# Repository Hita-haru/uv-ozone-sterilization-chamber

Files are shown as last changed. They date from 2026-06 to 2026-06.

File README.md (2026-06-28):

# UV and Ozone Sterilization chamber
## Description
This is a project to build a chamber that sterilizes objects using a UV lamp (wavelength 185 nm) that generates ozone.
## Reason for creating this
Have you ever been bothered by annoying mold or bacteria?
For example, a dishcloth that won’t lose its smell no matter how much you wash it, a lunchbox that goes bad as soon as you leave it out for a bit, a rubber duck toy that gets moldy the moment you leave it in the bathroom, or culture media that gets contaminated no matter how clean you keep it—I think everyone has struggled with these issues at least once.
I decided to create this because I wanted to solve those problems.
## Print settings
We strongly recommend using a high-strength gyroid for the infill!  
At the very least, please avoid using weak infills like Lightning. If you accidentally bump it while using it, it will shatter and emit dangerous UV rays, which is extremely hazardous!  
For the same reason, please set the infill to 25% or higher.  
Also, since we’ll be using insert nuts, set the number of wall lines to 4 or more.  
## Assembly Instructions
1. Wire the components
Please wire the components according to the wiring diagram. However, leave the wiring between the CCFL inverter and the UVC bulb, as well as the reset button (GPIO 4), unconnected.
2. Throw the components into the printed box.
Throw them into the box on the right labeled “Sterilization Chamber” and screw in the rotary encoder and other parts. Be sure to solder the reset button and UVC bulb in place after installing them. Otherwise, you’ll look like an idiot.
3. Glue the boxes together. For the large box, attach the side with the two small holes; for the small box, attach the side without a wall.
4. Insert the insert nuts.
Use a soldering iron or something similar to screw them into the holes. These are located on the bottom of the large lid, the bottom of the large box, the top of the interior, and the back of the small box.
5. Secure them with screws.
## Screenshots
### Prented result (CAD Screenshot)
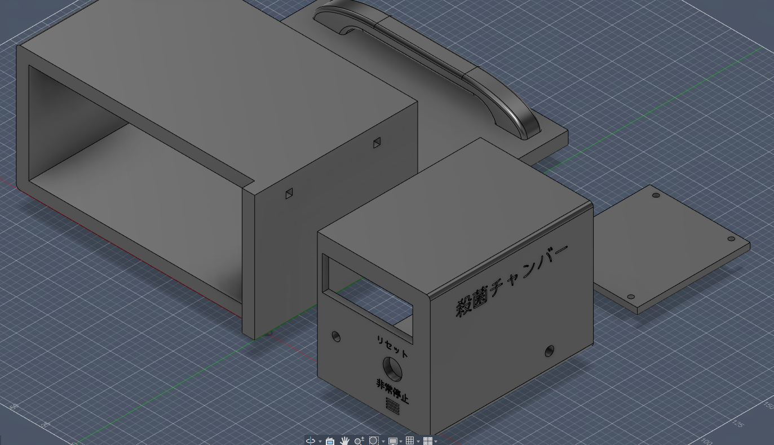
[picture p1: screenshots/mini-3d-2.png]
Printed result

### Writing diagram
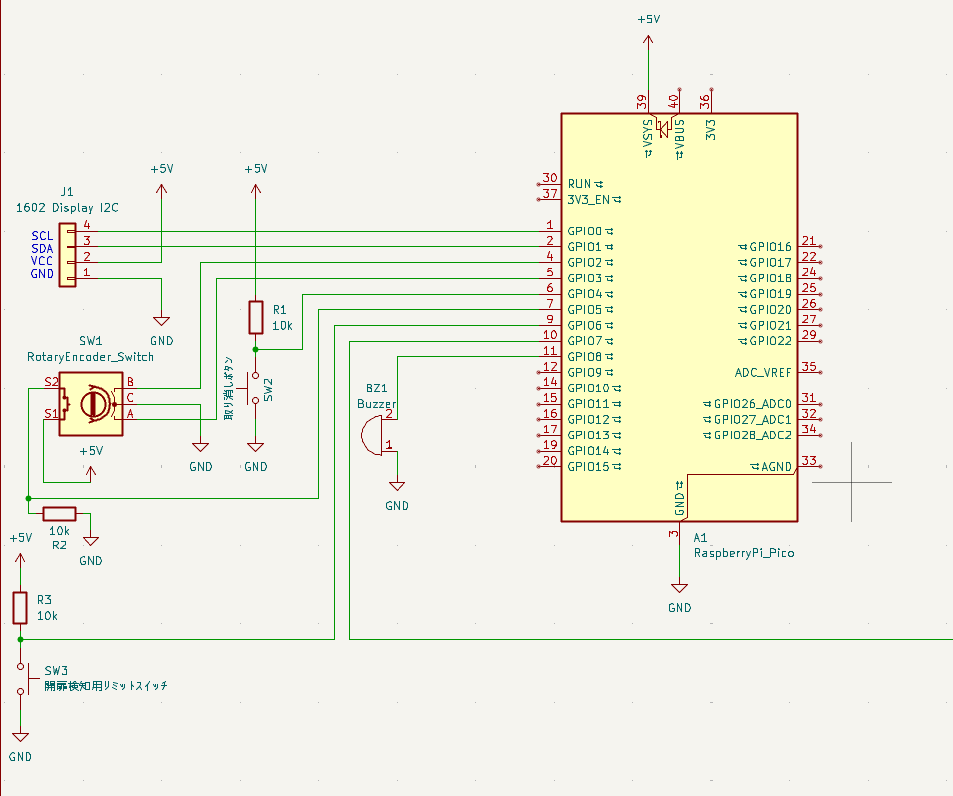
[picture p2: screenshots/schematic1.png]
Writing diagram1
  
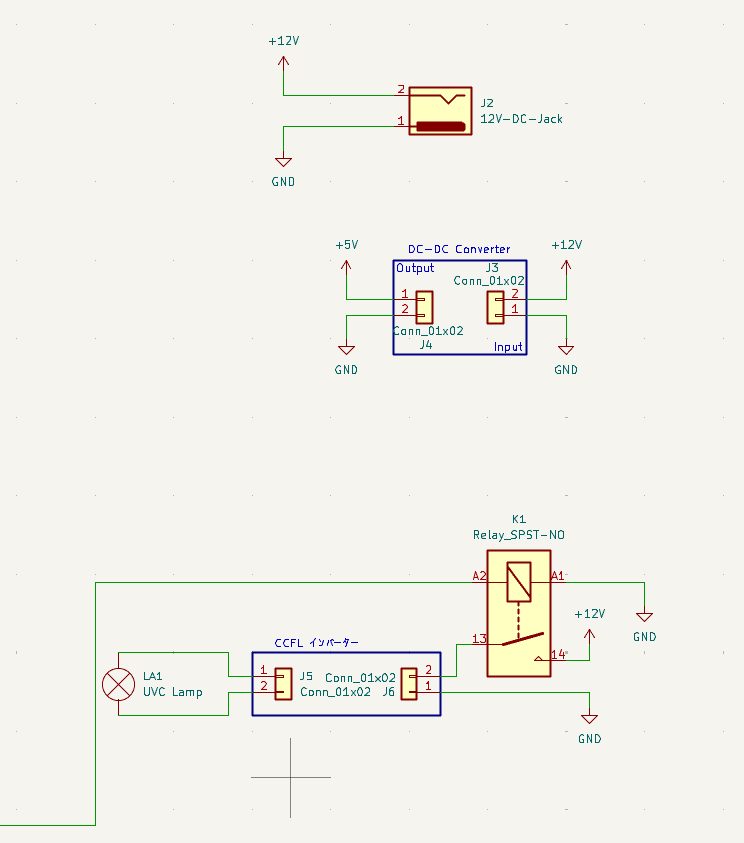
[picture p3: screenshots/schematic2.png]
Writing diagram2

## BOM
### **Be sure to select the M3xL4xOD4.5 insert nut!!!**
You'll need M3 screws that are about 3 mm and 10 mm long. A set might be cheaper.  

| Name | Quantity | Price(Per piece)$ | URL |
|---|---|---|---|
| Rotary Encoder  | 1 | 1.78 | https://ja.aliexpress.com/item/1005007644083514.html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 |
| Push switch | 1 | 0.71 | https://ja.aliexpress.com/item/1005009192896801.html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 |
| I2C 1602 LCD | 1 | 2.91 | https://ja.aliexpress.com/item/1005006964073869.html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 |
| Hinge 27x36mm | 2 | 1.465 | https://ja.aliexpress.com/item/1005011864985082.html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 |
| Doorstop | 1 | 1.7 | https://ja.aliexpress.com/item/1005006996924840.html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 |
| DC Jack 5.5x2.1 | 1 | 0.373 | https://ja.aliexpress.com/item/1005007870346260.html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 |
| Buzzer | 1 | 0.678 | https://ja.aliexpress.com/item/1005011934130065.html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 |
| DC-DC Converter | 1 | 1.4 | https://ja.aliexpress.com/item/1005006361814667.html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 |
| Relay Module | 1 | 2.58 | https://ja.aliexpress.com/item/1005011855111730.html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 |
| CCFL Inverter | 1 | 4.47 | https://ja.aliexpress.com/item/32873910106.html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 |
| UVC Bulb | 1 | 1.77 | https://ja.aliexpress.com/item/1005006289009903.html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 |
| E17 Bulb socket | 1 | 1.77 | https://ja.aliexpress.com/item/1005010153274458.html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 |
| Limit switch | 1 | 0.1915 | https://ja.aliexpress.com/item/1005009264525026.html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 |
| 10K Resistor | 3 | 0.0188 | https://ja.aliexpress.com/item/1005009330094258.html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 |
| RP2040 Devboard | 1 | 1.69 | https://ja.aliexpress.com/item/1005009068473196.html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 |
| Aluminum tape | 1 | 1.75 | https://ja.aliexpress.com/item/1005007698325860.html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 |
| 12V AC Adapter  | 1 | 3.65 (US Plug) | https://ja.aliexpress.com/item/1005010218801366.html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 |
| Insert nats | 14 | 0.122 | https://ja.aliexpress.com/item/1005006071488810.html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 |
| M3 Screws | 14 | 0.016921052631579 | https://ja.aliexpress.com/item/1005007399285653.html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 |

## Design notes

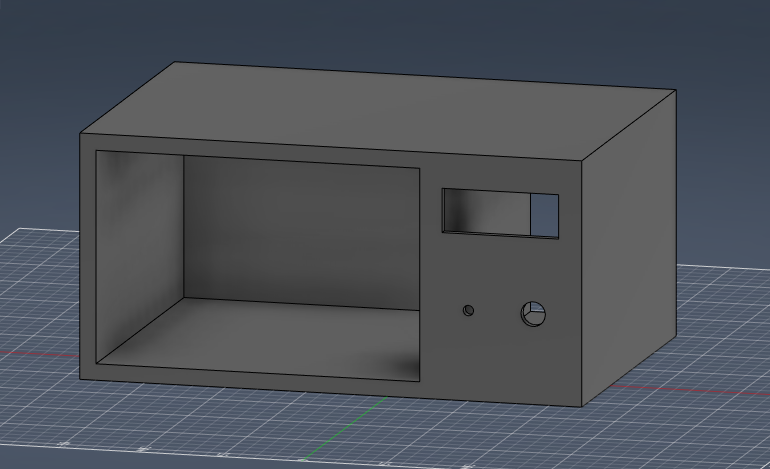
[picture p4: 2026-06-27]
screenshots/norm-3d-2.png

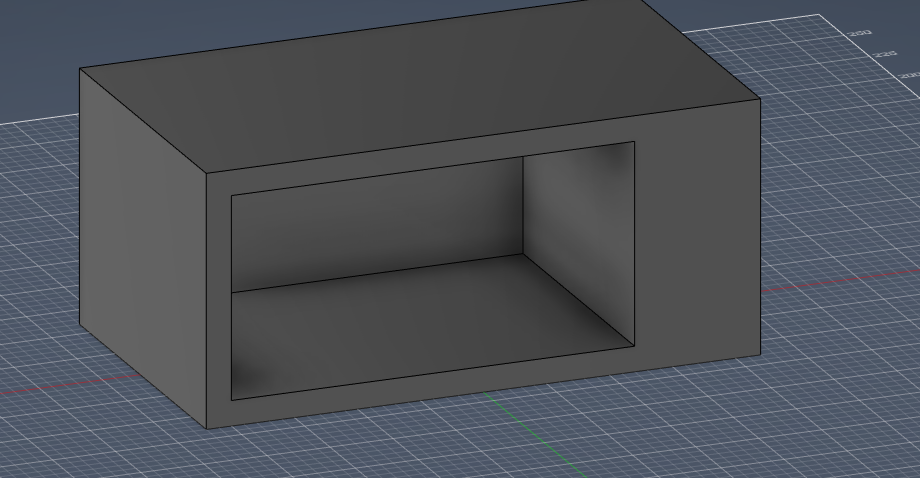
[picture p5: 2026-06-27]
screenshots/norm-3d-1.png

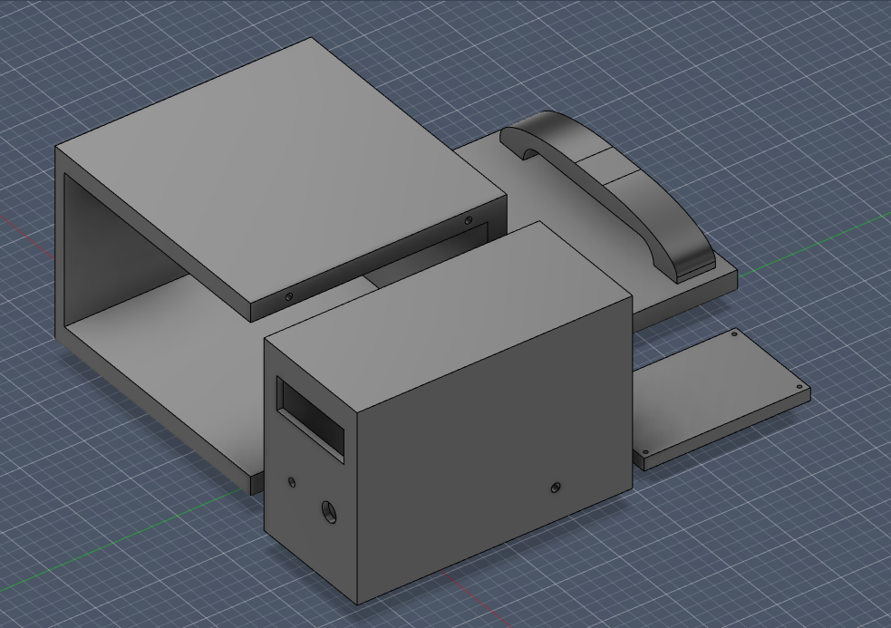
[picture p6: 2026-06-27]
screenshots/norm-3d-4.png

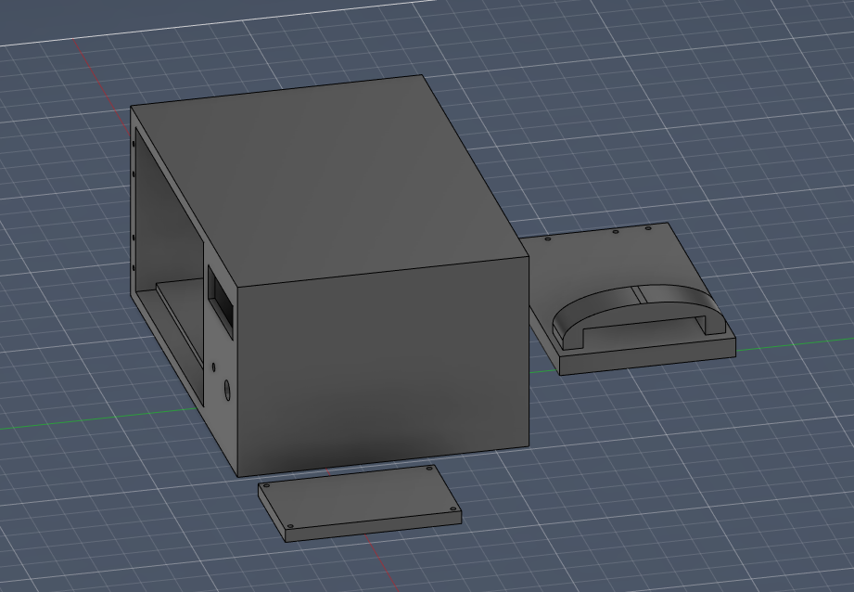
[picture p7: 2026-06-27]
screenshots/norm-3d-3.png

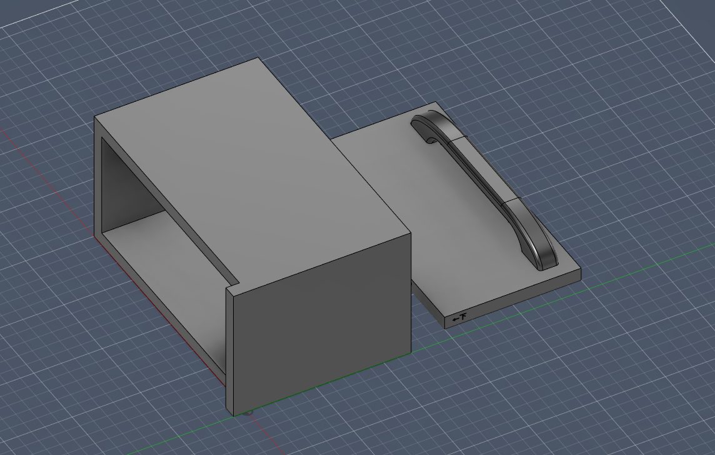
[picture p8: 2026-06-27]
screenshots/mini-3d-1.png

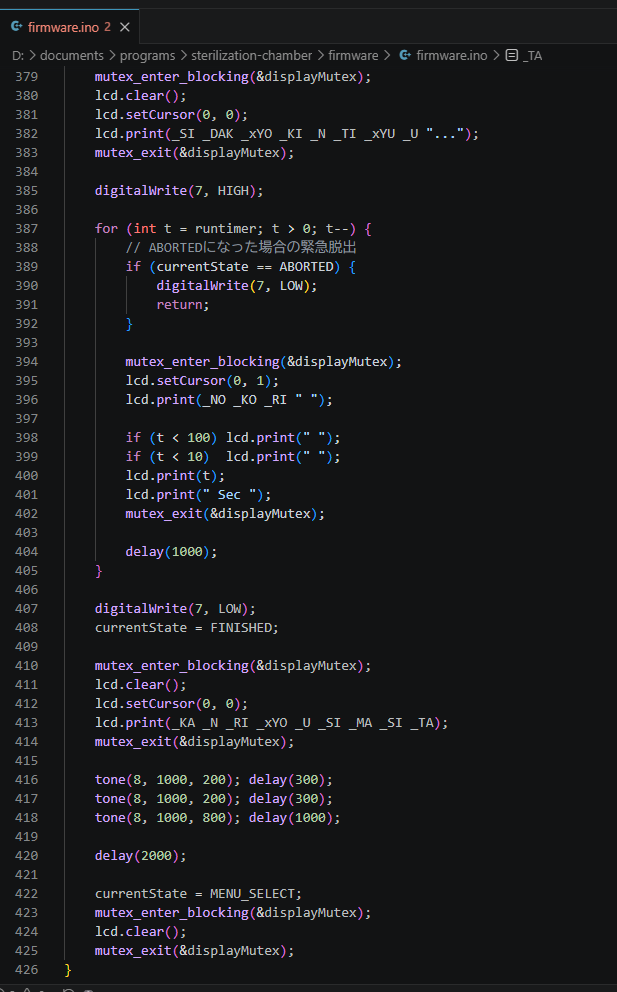
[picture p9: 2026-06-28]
screenshots/firmware.png

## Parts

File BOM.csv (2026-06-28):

Name | Quantity | Price
Rotary Encoder | 1 | 1.78
Push switch | 1 | 0.71
I2C 1602 LCD | 1 | 2.91
Hinge 27x36mm | 2 | 1.465
Doorstop | 1 | 1.7
DC Jack 5.5x2.1 | 1 | 0.373
Buzzer | 1 | 0.678
DC-DC Converter | 1 | 1.4
Relay Module | 1 | 2.58
CCFL Inverter | 1 | 4.47
UVC Bulb | 1 | 1.77
E17 Bulb socket | 1 | 1.77
Limit switch | 1 | 0.1915
10K Resistor | 3 | 0.0188
RP2040 Devboard | 1 | 1.69
Aluminum tape | 1 | 1.75
12V AC Adapter | 1 | 3.65 (US Plug)
Insert nats | 14 | 0.122
M3 Screws | 14 | 0.016921052631579

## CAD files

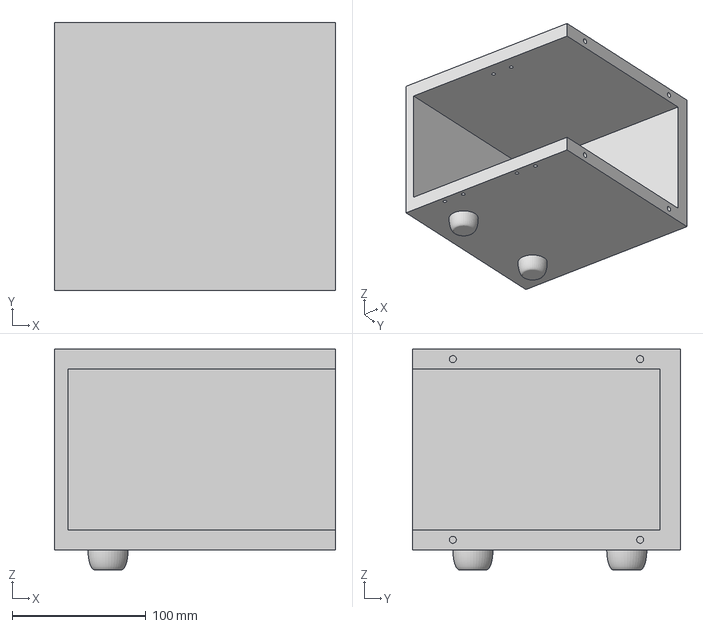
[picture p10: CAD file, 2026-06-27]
3d/deceased/main-box.3mf
210.0 x 200.0 x 165.0 mm

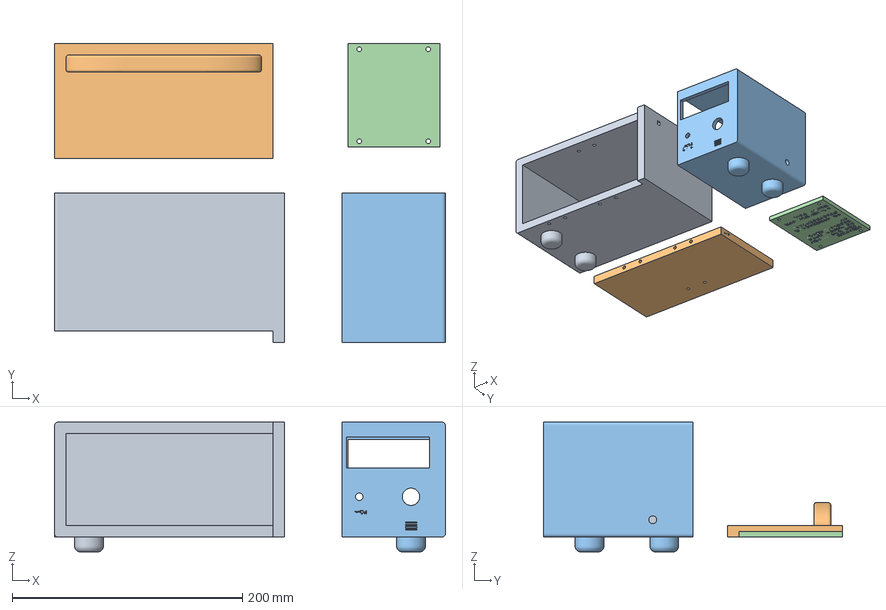
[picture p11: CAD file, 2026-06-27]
3d/sterilization-chamber-mini.3mf
340.0 x 260.0 x 113.0 mm
ボディ1
ボディ2
ボディ3
ボディ4

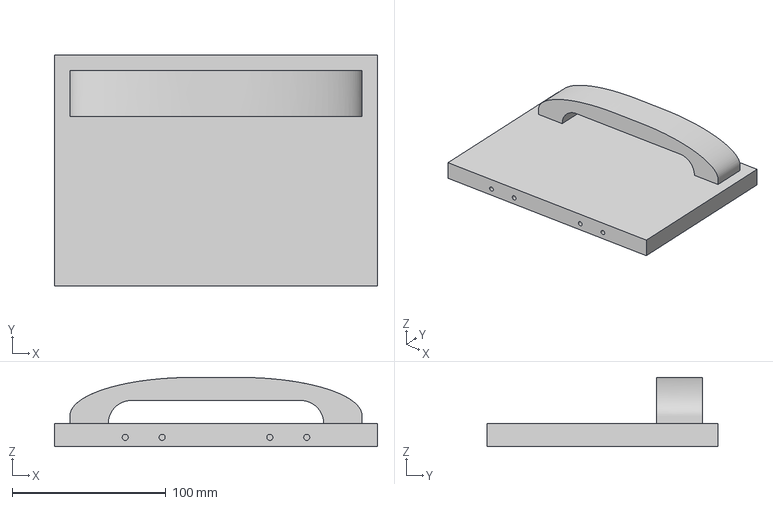
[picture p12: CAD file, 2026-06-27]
3d/deceased/front-door.3mf
210.0 x 150.0 x 45.0 mm

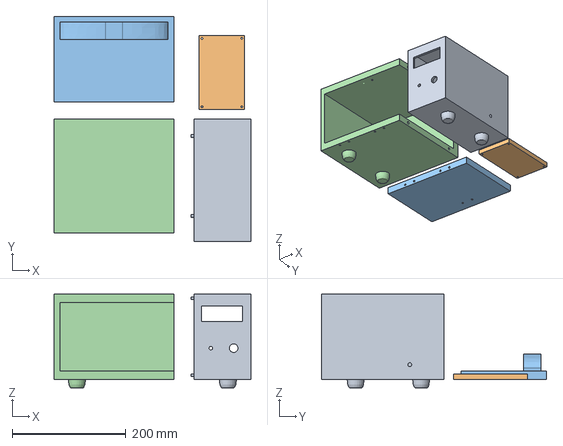
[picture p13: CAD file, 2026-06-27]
3d/deceased/sterilization-chamber.step
345.0 x 395.0 x 165.0 mm

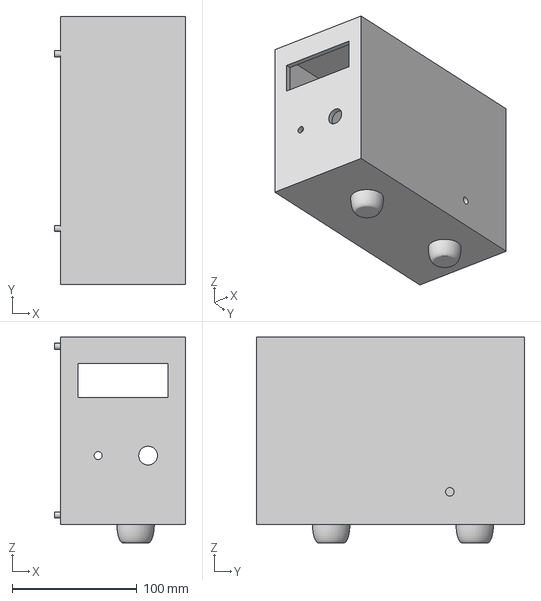
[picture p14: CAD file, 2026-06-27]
3d/deceased/circuit-box.3mf
105.0 x 215.0 x 165.0 mm

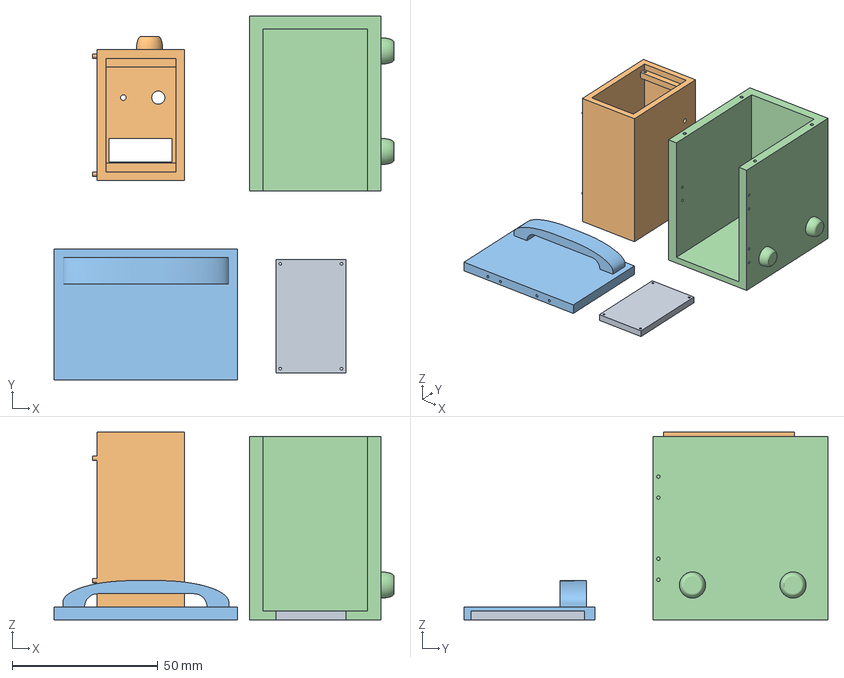
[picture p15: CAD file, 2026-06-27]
3d/deceased/backpanel.3mf
116.7 x 124.9 x 64.5 mm
ボディ2
ボディ1
ボディ5
ボディ6

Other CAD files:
sterilization-chamber.gcode.3mf
3d/deceased/sterilization-chamber.dxf
3d/deceased/sterilization-chamber.obj
3d/deceased/sterilization-chamber.stl
3d/sterilization-chamber-mini.f3d
3d/sterilization-chamber-mini.stl

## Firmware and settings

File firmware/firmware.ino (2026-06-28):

#include <Wire.h>
#include <LiquidCrystal_I2C.h>
#include <RotaryEncoder.h>
#include <pico/mutex.h>

#define _A     "\xB1" // ｱ
#define _I     "\xB2" // ｲ
#define _U     "\xB3" // ｳ
#define _E     "\xB4" // ｴ
#define _O     "\xB5" // ｵ
#define _KA    "\xB6" // ｶ
#define _KI    "\xB7" // ｷ
#define _KU    "\xB8" // ｸ
#define _KE    "\xB9" // ｹ
#define _KO    "\xBA" // ｺ
#define _SA    "\xBB" // ｻ
#define _SI    "\xBC" // ｼ
#define _SU    "\xBD" // ｽ
#define _SE    "\xBE" // ｾ
#define _SO    "\xBF" // ｿ
#define _TA    "\xC0" // ﾀ
#define _TI    "\xC1" // ﾁ
#define _TU    "\xC2" // ﾂ
#define _TE    "\xC3" // ﾃ
#define _TO    "\xC4" // ﾄ
#define _HA    "\xCA" // ﾊ
#define _HI    "\xCB" // ﾋ
#define _HU    "\xCC" // ﾌ
#define _HE    "\xCD" // ﾍ
#define _HO    "\xCE" // ﾎ
#define _MA    "\xCF" // ﾏ
#define _MI    "\xD0" // ﾐ
#define _MU    "\xD1" // ﾑ
#define _ME    "\xD2" // ﾒ
#define _MO    "\xD3" // ﾓ
#define _RA    "\xD7" // ﾗ
#define _RI    "\xD8" // ﾘ
#define _RU    "\xD9" // ﾙ
#define _RE    "\xDA" // ﾚ
#define _RO    "\xDB" // ﾛ
#define _N     "\xDD" // ﾝ
#define _CHO   "\xB0" // ｰ (長音)

#define _DAK   "\xDE" // ﾞ (濁点)
#define _HAN   "\xDF" // ﾟ (半濁点)

// --- 液晶内蔵の便利記号 ---
#define _DEG   "\xDF" // ° (度・半濁点と同じ形状です)
#define _ARR_R "\x7E" // → (右矢印)
#define _ARR_L "\x7F" // ← (左矢印)
#define _DIV   "\xFD" // ÷ (割り算記号)
#define _YEN   "\x5C" // ¥ (フォントにより円マークになります)
#define _MID   "\xA5" // ・（中点）

#define _NA    "\xC5" // ﾅ
#define _NI    "\xC6" // ﾆ
#define _NU    "\xC7" // ﾇ
#define _NE    "\xC8" // ﾈ
#define _NO    "\xC9" // ﾉ

// --- ヤ行 ---
#define _YA    "\xD4" // ﾔ
#define _YU    "\xD5" // ﾕ
#define _YO    "\xD6" // ﾖ

// --- ワ・ヲ ---
#define _WA    "\xDC" // ﾜ
#define _WO    "\xA6" // ｦ

// --- ァィゥェォ（小文字） ---
#define _xA    "\xA7" // ｧ
#define _xI    "\xA8" // ｨ
#define _xU    "\xA9" // ｩ
#define _xE    "\xAA" // ｪ
#define _xO    "\xAB" // ｫ

// --- ャュョッ（小文字） ---
#define _xYA   "\xAC" // ｬ
#define _xYU   "\xAD" // ｭ
#define _xYO   "\xAE" // ｮ
#define _xTU   "\xAF" // ｯ

void menuController();
void lcdHandler();
void kaoHandler(int kaomode);
void showError(int errorcode);
void uvTimer(int runtimer);

auto_init_mutex(displayMutex);

LiquidCrystal_I2C lcd(0x3F, 16, 2);
RotaryEncoder encoder(3, 2, RotaryEncoder::LatchMode::FOUR3);
int lcdmode = 0;
long newpos = 0;
int menuNum = 0;
volatile bool menuWarikomi = 0;
bool isTimerStarted = false;
enum State {
    INITIALIZING,
    MENU_SELECT,
    RUNNING,
    FINISHED,
    ABORTED,
    ERROR
};
volatile State currentState = MENU_SELECT;

void setup() {
    pinMode(4, INPUT); // リセットスイッチ 
    pinMode(5, INPUT); // ロータリーエンコーダー（押し込み）
    pinMode(6, INPUT); // 開扉検知用リミットスイッチ
    pinMode(7, OUTPUT); // UVCランプ用リレー
    pinMode(8, OUTPUT); // ブザー

    Wire.begin();
    mutex_enter_blocking(&displayMutex);
    lcd.init();
    lcd.backlight();
    lcd.clear();
    lcd.setCursor(0, 0);
    lcd.print(_SI _xYO _KI _KA _TI _xYU _U "...");
    mutex_exit(&displayMutex);
    kaoHandler(3);
    mutex_enter_blocking(&displayMutex);
    lcd.clear();
    mutex_exit(&displayMutex);
    kaoHandler(2);
    lcdHandler();
}

void loop() {

}

void loop1() {
    if(currentState == MENU_SELECT) {
        encoder.tick();
        newpos = encoder.getPosition();
        menuController();
    }
}

void menuController() {
    int timertime = 0;
    static long oldpos = 0;
    const int numOptions = 5; // メニューの選択肢の数 - 1
    if(newpos != oldpos) {
        RotaryEncoder::Direction dir = encoder.getDirection();
        if(dir == RotaryEncoder::Direction::CLOCKWISE) {
            if(menuNum >= numOptions) {
                menuNum = 0;
            } else {
                menuNum++;
            }
        } else if(dir == RotaryEncoder::Direction::COUNTERCLOCKWISE) {
            if(menuNum <= 0) {
                menuNum = numOptions;
            } else {
                menuNum--;
            }
        }
        oldpos = newpos;
    }
    mutex_enter_blocking(&displayMutex);
    lcd.setCursor(0, 1);
    lcd.print(_ME _NI _xYU _CHO);
    lcd.setCursor(0, 0);
    switch(menuNum) {
        case 0:
            timertime = 10;
            lcd.print(_SA _SA _xTU _TO _SI _DAK _xYO _KI _N);
            break;
        case 1:
            timertime = 30;
            lcd.print(_SU _KO _SI _SI _DAK _xYO _KI _N);
            break;
        case 2:
            timertime = 60;
            lcd.print(_HU _TU _U _NI _SI _DAK _xYO _KI _N);
            break;
        case 3:
            timertime = 90;
            lcd.print(_SI _xTU _KA _RI _SHI _DAK _xYO _KI _N);
            break;
        case 4:
            timertime = 120;
            lcd.print(_SI _DAK _xTU _KU _RI _SI _DAK _xYO _KI _N);
            break;
        case 5:
            timertime = 160;
            lcd.print(_SI _DAK _xE _NO _SA _I _TO _DAK _MO _CHO _TO _DAK);
            break;
        default:
            showError(1);
            menuNum = 0;
            break;
    }
    mutex_exit(&displayMutex);
    if(digitalRead(5) == HIGH) {
        currentState = RUNNING;
        uvTimer(timertime);
    }
}

void lcdHandler() {
    int currentKao = 2;
    int volatile emotion = 0;
    
    mutex_enter_blocking(&displayMutex);
    lcd.setCursor(0, 0);
    lcd.print("LCD" _HA _N _TO _DAK _RA _NI _I _KO _U);
    mutex_exit(&displayMutex);
    while(1) {
        if(digitalRead(6) != HIGH && currentState == RUNNING) { //動作中に開扉
            digitalWrite(7, LOW);
            currentState = ABORTED;
            mutex_enter_blocking(&displayMutex);
            lcd.setCursor(0, 0);
            lcd.print(_HI _SI _DAK _xYO _U _TE _I _SI "!!!");
            mutex_exit(&displayMutex);
            kaoHandler(5);
            for(int i = 0; i <= 20; i++) {
                tone(8, 660, 500);
                delay(300);
            }
            while(1) {
                mutex_enter_blocking(&displayMutex);
                lcd.setCursor(0, 0);
                lcd.print(_RI _SE _xTU _TO _HO _DAK _TA _N _WO _NA _KA _DAK _O _SI);
                mutex_exit(&displayMutex);
                kaoHandler(7);
                if(digitalRead(4)) {
                    mutex_enter_blocking(&displayMutex);
                    lcd.setCursor(0, 0);
                    lcd.print(_RI _SE _xTU _TO _SI _TE _I _MA _SU);
                    mutex_exit(&displayMutex);
                    kaoHandler(3);
                    currentState = MENU_SELECT;
                    break;
                }
            }
        } else if(digitalRead(4) == HIGH && currentState == RUNNING) {
            digitalWrite(7, LOW);
            currentState = ABORTED;
            mutex_enter_blocking(&displayMutex);
            lcd.clear();
            lcd.setCursor(0, 0);
            lcd.print(_TE _I _SI _SI _MA _SI _TA);
            mutex_exit(&displayMutex);
            kaoHandler(4);
            tone(8, 660, 1000);
        }
        if(emotion == 0) { // 普通
            if((millis() / 500) % 10 == 0) {
                currentKao = 0;
            } else {
                currentKao = 2;
            }
        } else if(emotion == 1) { // 混乱
            currentKao = 5;
        }
        kaoHandler(currentKao);
        delay(50);
    }
}

void kaoHandler(int kaomode) {
    mutex_enter_blocking(&displayMutex);
    switch(kaomode) {
        case 0: // (-_-)
            lcd.setCursor(10, 1);
            lcd.print("(-_-)");
            break;
        case 1: // (・_・)
            lcd.setCursor(10, 1);
            lcd.print("("  _MID "_" _MID ")");
            break;
        case 2: // (^_^)
            lcd.setCursor(10, 1);
            lcd.print("(^_^)");
            break;
        case 3: // Zzz (-_-)
            lcd.setCursor(10, 1);
            lcd.print("(-_-)");
            for(int j = 0; j <= 2; j++) {
                for(int i = 0; i <= 3; i++) {
                    lcd.setCursor(6, 1);
                    if(i == 0) {
                        lcd.print("   ");
                    } else if(i == 1) {
                        lcd.print("  z");
                    } else if(i == 2) {
                        lcd.print(" zz");
                    } else if(i == 3) {
                        lcd.print("Zzz");
                    }
                    delay(500);
                }
            }
            break;
        case 4: // (>_<)
            lcd.setCursor(10, 1);
            lcd.print("(>_<)");
            break;
        case 5: // (@_@)
            lcd.setCursor(10, 1);
            lcd.print("(@_@)");
            break;
        case 6: // (#_#)
            lcd.setCursor(10, 1);
            lcd.print("(#_#)");
            break;
        case 7: // (;_;)
            lcd.setCursor(10, 1);
            lcd.print("(;_;)");
            break;
        default:
            lcd.setCursor(4, 1);
            lcd.print("Error (#_#)");
            break;
    }
    mutex_exit(&displayMutex);
}

void showError(int errorcode) {
    switch(errorcode) {
        case 0:
            mutex_enter_blocking(&displayMutex);
            lcd.clear();
            mutex_exit(&displayMutex);
            while(1) {
                kaoHandler(6);
                mutex_enter_blocking(&displayMutex);
                lcd.setCursor(0, 0);
                lcd.print(_E _RA _CHO _KA _DAK _HA _xTU _SE _I _SI _MA _SI _TA);
                delay(2000);
                lcd.clear();
                mutex_exit(&displayMutex);
                kaoHandler(5);
                mutex_enter_blocking(&displayMutex);
                lcd.setCursor(0, 0);
                lcd.print(_SA _I _KI _TO _DAK _U _SI _TE _KU _TA _DAK _SA _I);
                delay(2000);
                lcd.clear();
                mutex_exit(&displayMutex);
            }
            break;
        case 1:
            mutex_enter_blocking(&displayMutex);
            lcd.clear();
            mutex_exit(&displayMutex);
            kaoHandler(6);
            mutex_enter_blocking(&displayMutex);
            lcd.print(_E _RA _CHO _KA _DAK _HA _xTU _SE _I _SI _MA _SI _TA);
            mutex_exit(&displayMutex);
            delay(5000);
            break;
        default:
            break;
    }
}

void uvTimer(int runtimer) {
    if (digitalRead(6) != HIGH) {
        mutex_enter_blocking(&displayMutex);
        lcd.clear();
        lcd.setCursor(0, 0);
        lcd.print(_TO _HI _DAK _RA _KA _DAK _A _I _TE _I _MA _SU);
        mutex_exit(&displayMutex);
        tone(8, 440, 500);
        delay(2000);
        mutex_enter_blocking(&displayMutex);
        lcd.clear();
        mutex_exit(&displayMutex);
        currentState = MENU_SELECT;
        return;
    }

    mutex_enter_blocking(&displayMutex);
    lcd.clear();
    lcd.setCursor(0, 0);
    lcd.print(_SI _DAK _xYO _KI _N _TI _xYU _U "...");
    mutex_exit(&displayMutex);

    digitalWrite(7, HIGH);

    for (int t = runtimer; t > 0; t--) {
        // ABORTEDになった場合の緊急脱出
        if (currentState == ABORTED) {
            digitalWrite(7, LOW);
            return; 
        }

        mutex_enter_blocking(&displayMutex);
        lcd.setCursor(0, 1);
        lcd.print(_NO _KO _RI " ");

        if (t < 100) lcd.print(" ");
        if (t < 10)  lcd.print(" ");
        lcd.print(t);
        lcd.print(" Sec ");
        mutex_exit(&displayMutex);

        delay(1000);
    }

    digitalWrite(7, LOW);
    currentState = FINISHED;

    mutex_enter_blocking(&displayMutex);
    lcd.clear();
    lcd.setCursor(0, 0);
    lcd.print(_KA _N _RI _xYO _U _SI _MA _SI _TA);
    mutex_exit(&displayMutex);
    
    tone(8, 1000, 200); delay(300);
    tone(8, 1000, 200); delay(300);
    tone(8, 1000, 800); delay(1000);

    delay(2000);
    
    currentState = MENU_SELECT;
    mutex_enter_blocking(&displayMutex);
    lcd.clear();
    mutex_exit(&displayMutex);
}

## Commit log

2026-06-27 Push push push!!!
    [backpanel.3mf, circuit-box.3mf, front-door.3mf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]
2026-06-28 Added firmware and so on
    [backpanel.3mf, circuit-box.3mf, front-door.3mf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]
2026-06-28 Added BOM.csv
    [BOM.csv]
